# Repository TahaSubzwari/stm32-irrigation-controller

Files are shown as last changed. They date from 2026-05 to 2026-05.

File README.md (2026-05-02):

# STM32 Irrigation Controller

An embedded controller for a multi-zone irrigation system, built on the STM32 Nucleo-F401RE. The system manages a single pump and servo-driven distributor to fill a reservoir from an underground spring and irrigate three terraced zones at different elevations, all within a 24-hour cycle.

Developed for ECE 298 (Instrumentation & Prototyping Laboratory) at the University of Waterloo, Fall 2025.

---

## Features

* **Two-mode state machine** - `SETUP` mode for parameter entry over UART, `RUN` mode for autonomous 24-hour operation (scaled for demo purposes).
* **Configurable scheduling** - User specifies start/stop hours and pump speed (PWM duty cycle) for each of 4 pipelines (1 inlet + 3 zones) via serial terminal.
* **Manual control option** - Inlet pump speed can be driven by a potentiometer through ADC, mapped to PWM duty cycle in real time.
* **Servo-driven water distributor** - RGB LED indicates the active pipeline (purple/red/green/blue); servo rotates to the corresponding zone.
* **Real-time RPM measurement** - RPM pulses counted via GPIO interrupt over a fixed real-time interval (independent of the scaled simulation clock).
* **Ultrasonic depth sensing** - HC-SR04 driven by timer input capture; reservoir depth displayed as a percentage on a 7-segment timer board and over UART.
* **Empty-reservoir fault handling** - Motor shutoff and flashing white RGB indicator if the reservoir hits 0% during operation.

---

## Hardware

|Component|Role|
|-|-|
|STM32 Nucleo-F401RE|Main controller (ARM Cortex-M4)|
|L9110 motor driver + brushed DC motor|Pump, dual-direction PWM|
|SG90 servo motor|Water distributor selector|
|HC-SR04 ultrasonic sensor|Reservoir depth measurement|
|RPM Sensor + slotted wheel|RPM feedback on motor shaft|
|Lab Timer Board (dual 7-segment)|Water depth percentage display|
|RGB LED|Active pipeline indicator|
|Potentiometer|Manual speed control (inlet only)|

A custom 2-layer shield PCB was designed in Proteus to stack onto the Nucleo header. The board was not fabricated due to course timeline constraints.

---

## Hardware Design

### Schematic

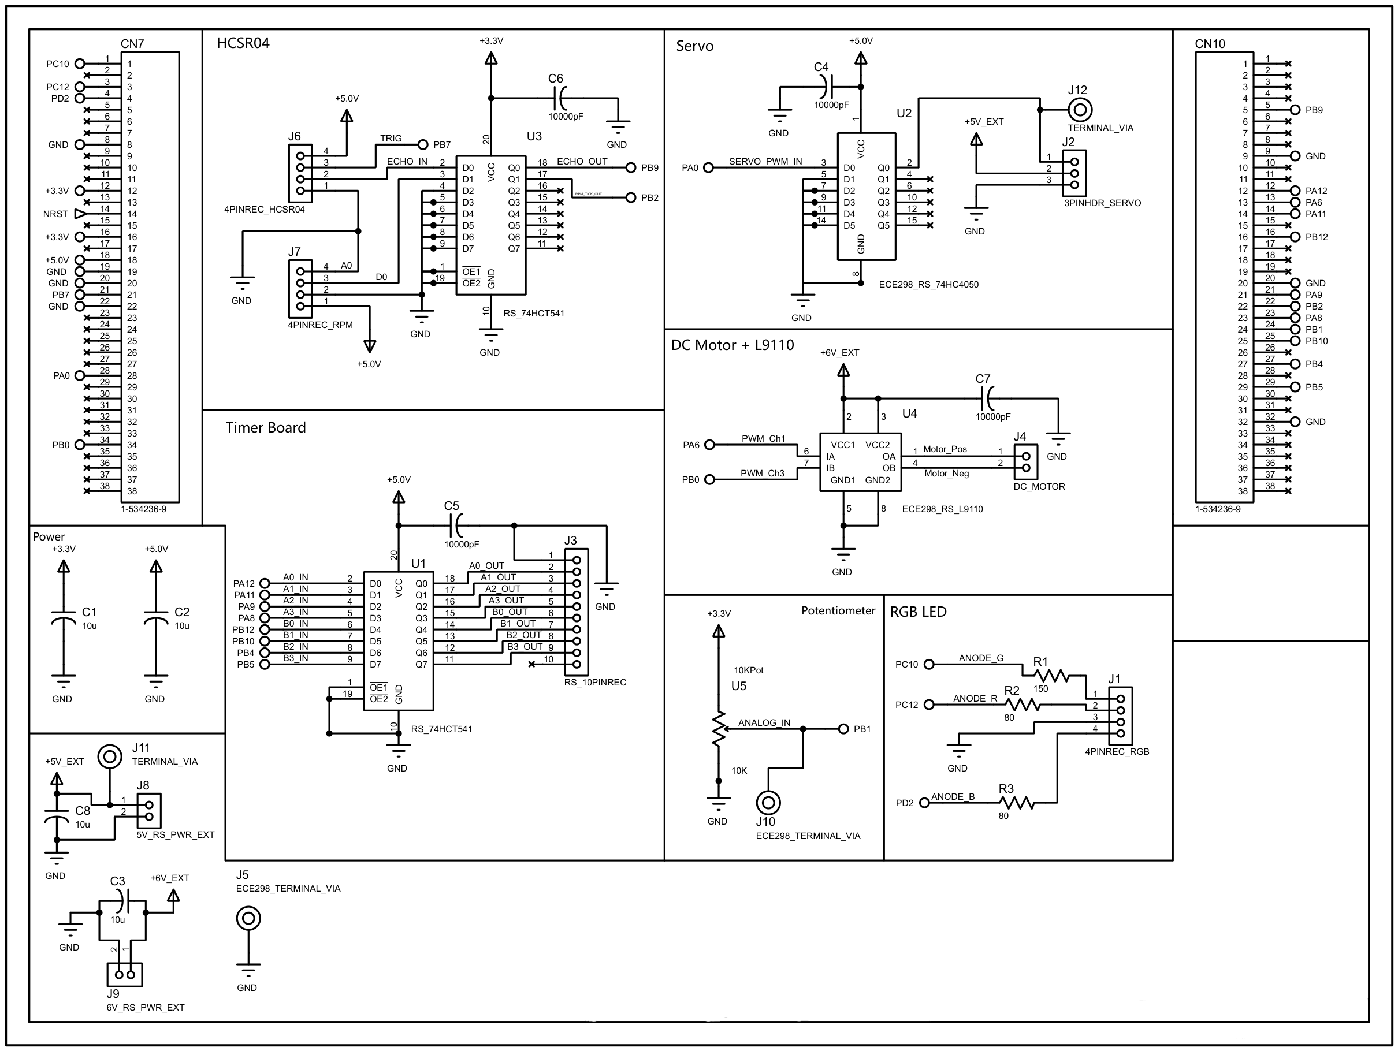
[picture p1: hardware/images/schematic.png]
Schematic


### PCB Layout

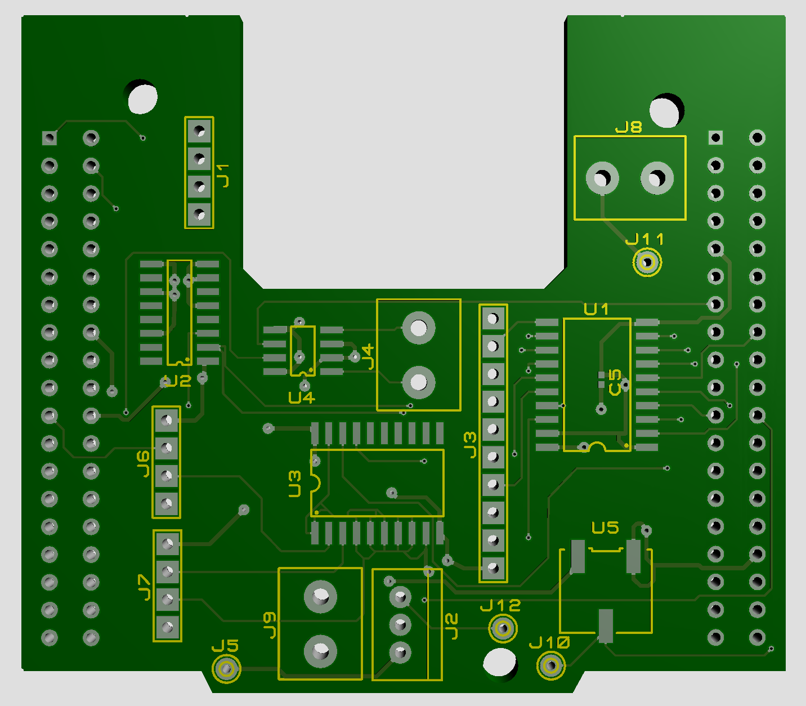
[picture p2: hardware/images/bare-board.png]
PCB Bare

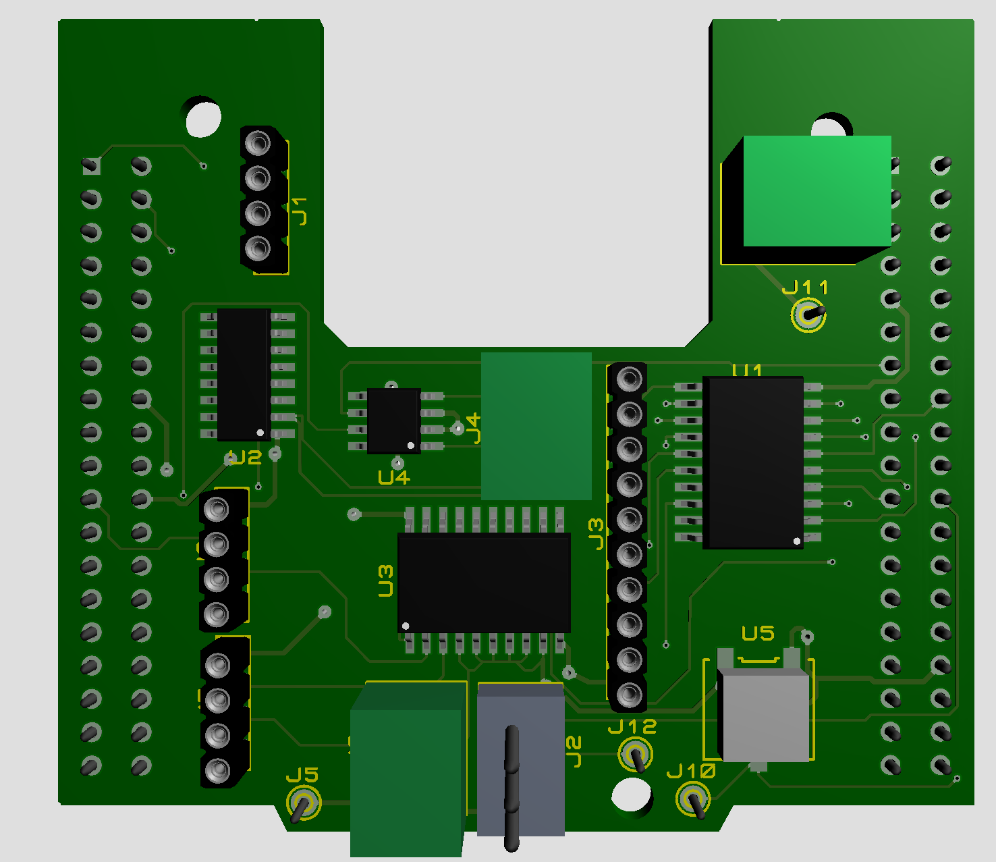
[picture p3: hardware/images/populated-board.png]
PCB Populated


---

## Architecture

### Peripherals

|Timer|Function|
|-|-|
|TIM2 CH1|Servo PWM (50 Hz, 1–2 ms pulse width)|
|TIM3 CH1/CH3|DC motor PWM (forward / reverse via L9110)|
|TIM4 CH4|HC-SR04 echo input capture (both edges)|
|TIM5|Scaled wall-clock tick (12 s = 1 simulated hour)|

|Other|Function|
|-|-|
|ADC1 CH9|Potentiometer read (8-bit resolution)|
|USART2|Terminal I/O at 115200 baud|
|EXTI (RPM\_TICK pin)|RPM pulse counter|
|GPIO|7-segment digit drive, RGB LED, mode LED, B1 button|

### Control flow

1. **Reset** → `SETUP` mode. Green LED off. UART prompts for pipeline assignments, PWM options, and start/stop hours for each of 4 pipelines.
2. Setup parameters echoed back to terminal. Green LED flashes; system waits for B1 (blue user button).
3. **B1 press** → `RUN` mode. Green LED solid on. Scaled clock starts at hour 0.
4. Each simulated hour: select active pipeline based on schedule, set servo + RGB + motor PWM, sample reservoir depth, measure RPM over real-time window, log status row to UART, update 7-segment display.
5. **Hour 24** → motor off, green LED off, system halts until reset.
6. **Reservoir empty event** → immediate motor shutoff, flashing white RGB, halt until reset.

### Status output

Hourly rows logged to UART in the format:

```
CLOCK : PIPE : PWM : RPM : DEPTH :
   0  :  0  :  0  : 142 :  87  :
   1  :  0  :  0  : 138 :  91  :
   ...
```

---

## What I'd Do Differently

This was a course project on a fixed timeline. With more time:

* **Revamp SETUP mode UART handling.** The blocking receive pattern is repeated for every prompt. A helper function or parameter table would clean this up significantly.
* **Use a struct for pipeline state.** Pipelines are tracked as parallel variables (`pipeA`, `pwmA`, `firstA`, `lastA`) instead of a single `Pipeline` struct, which inflates the schedule logic and makes adding pipelines tedious.
* **The PCB is unverified** - designed but not fabricated, so layout issues haven't been caught in hardware.

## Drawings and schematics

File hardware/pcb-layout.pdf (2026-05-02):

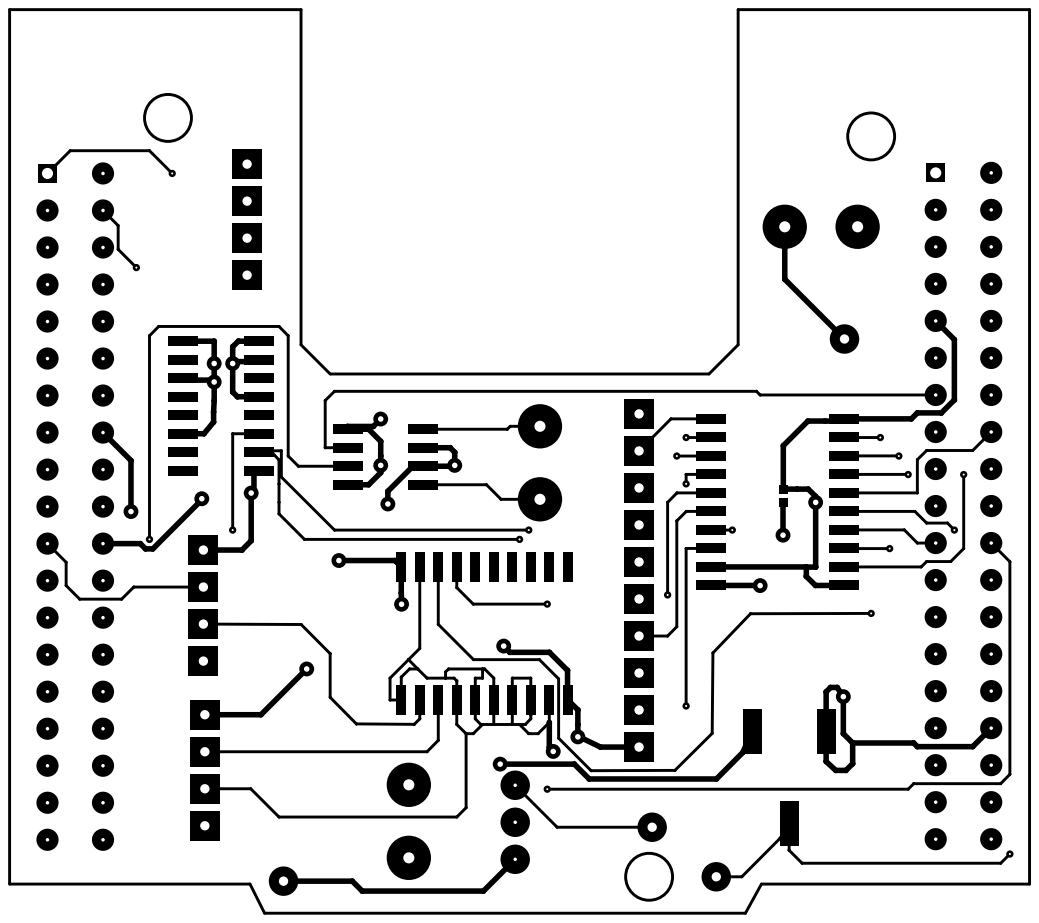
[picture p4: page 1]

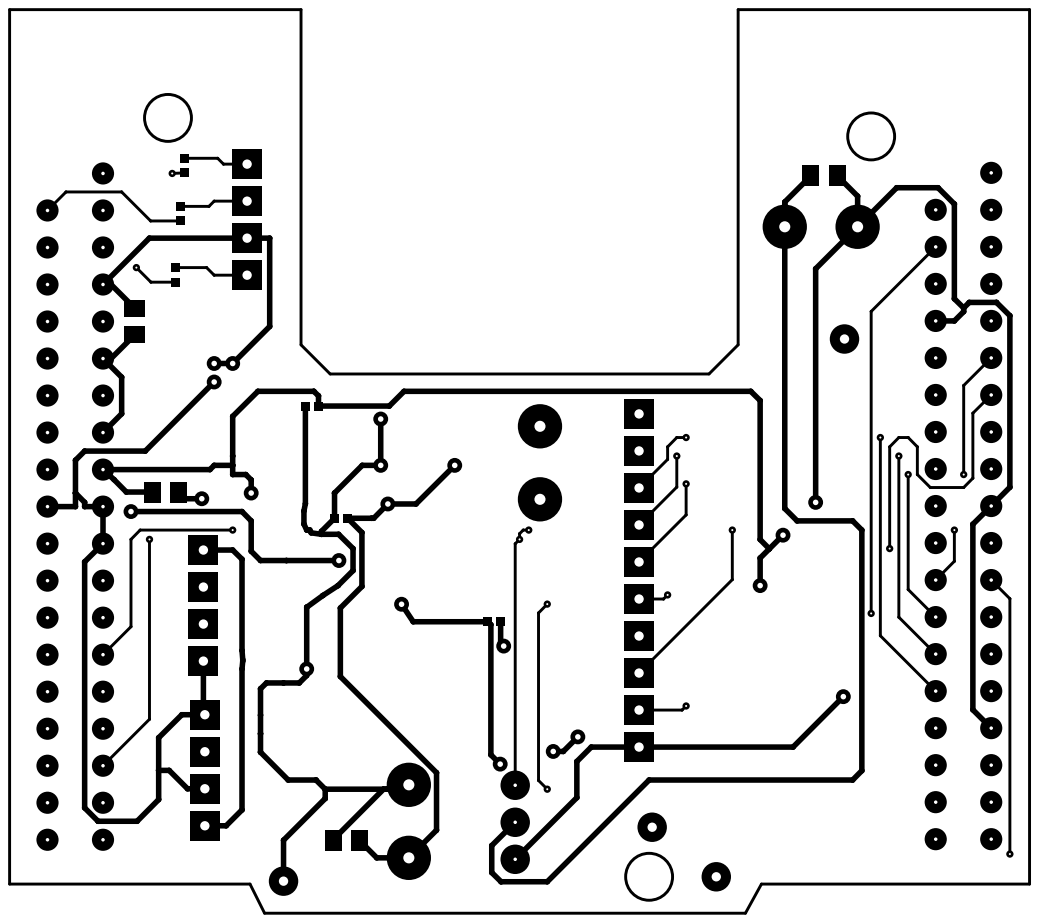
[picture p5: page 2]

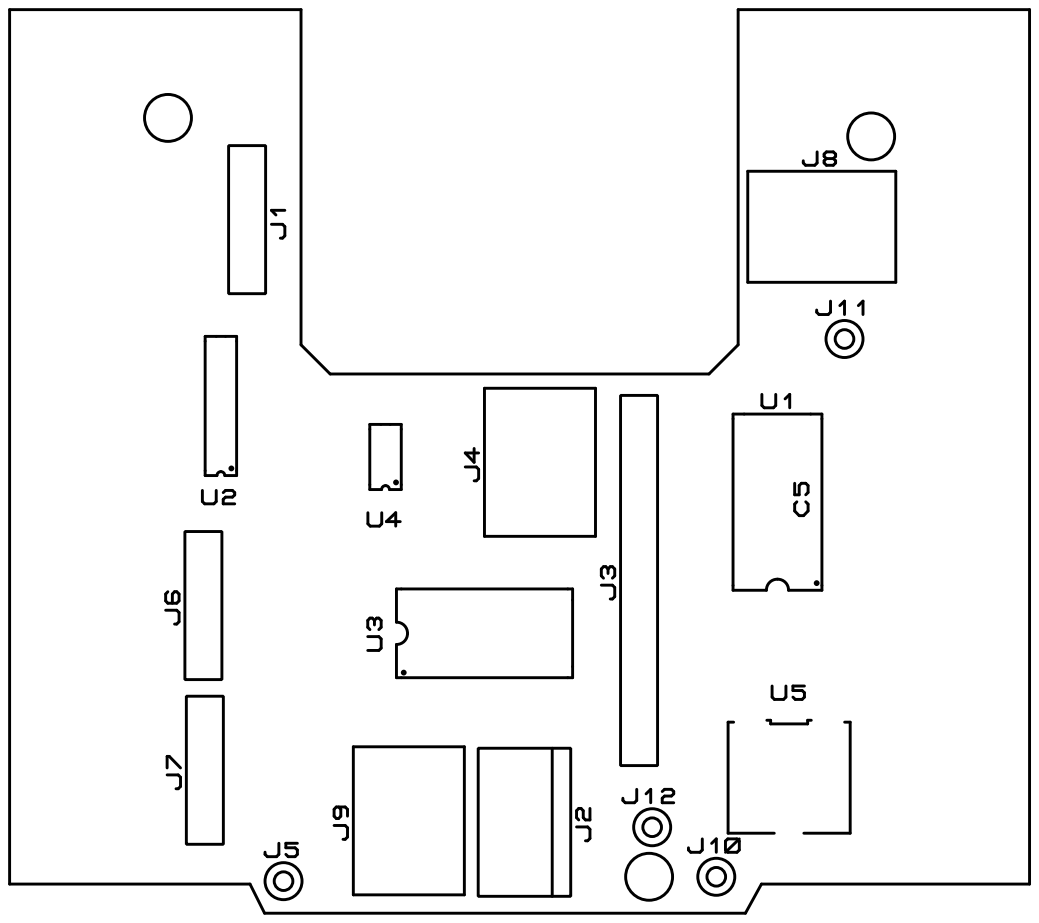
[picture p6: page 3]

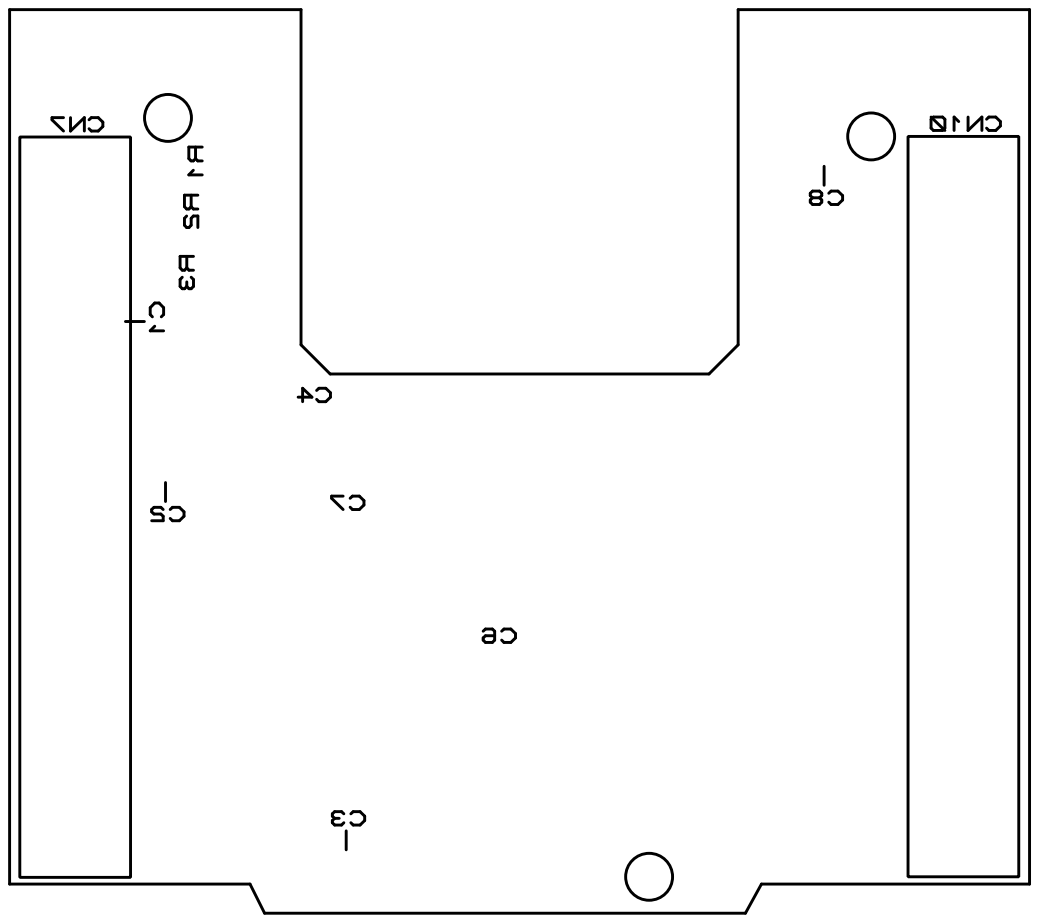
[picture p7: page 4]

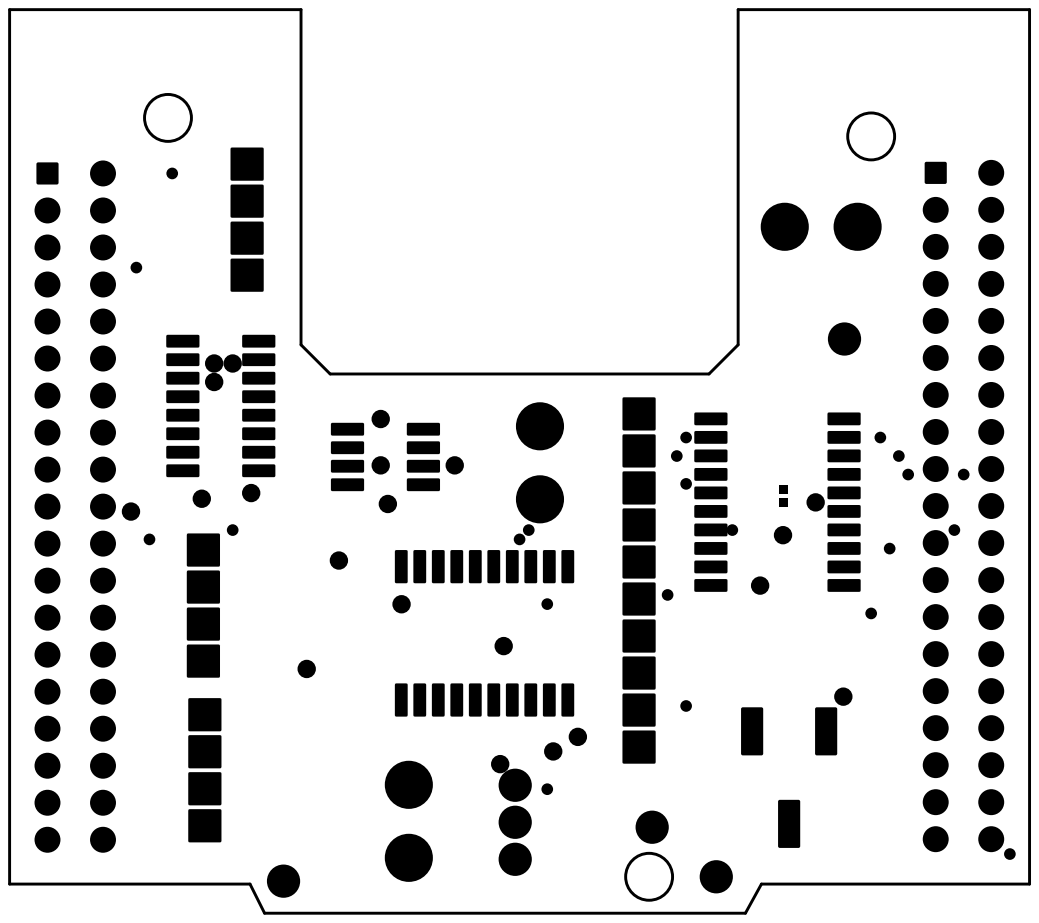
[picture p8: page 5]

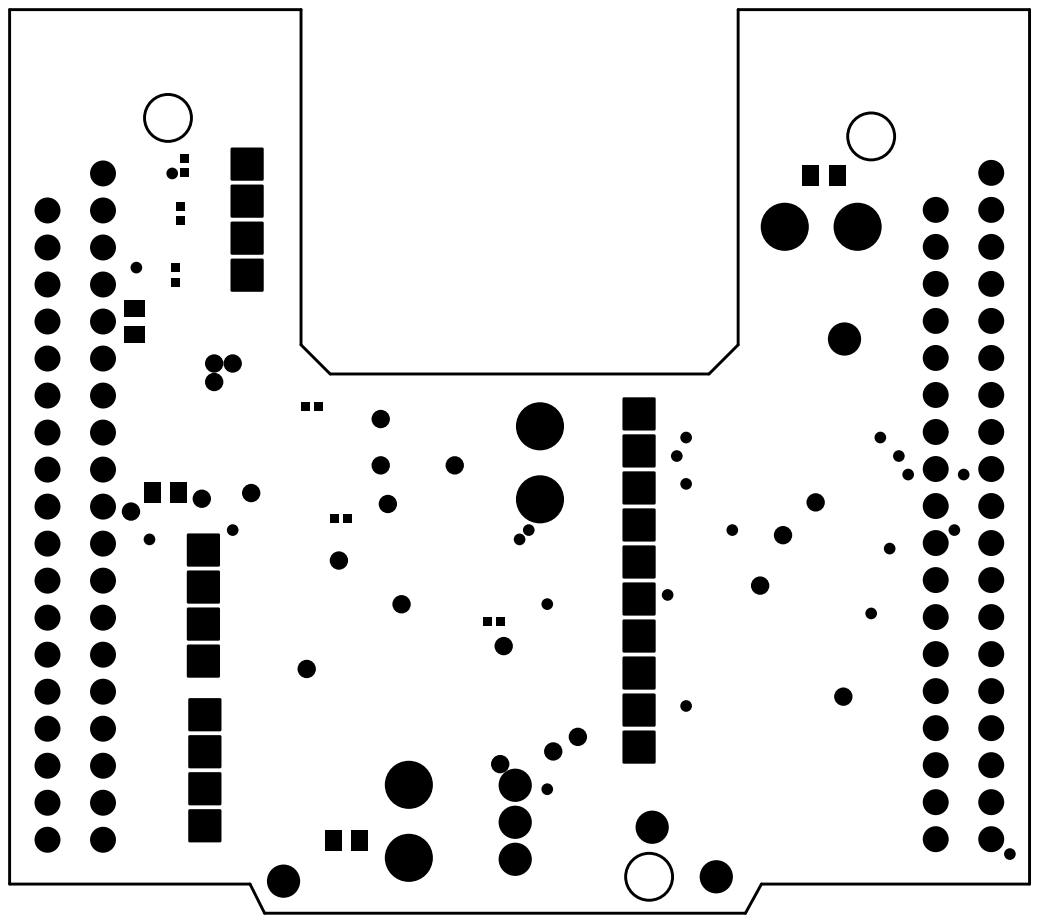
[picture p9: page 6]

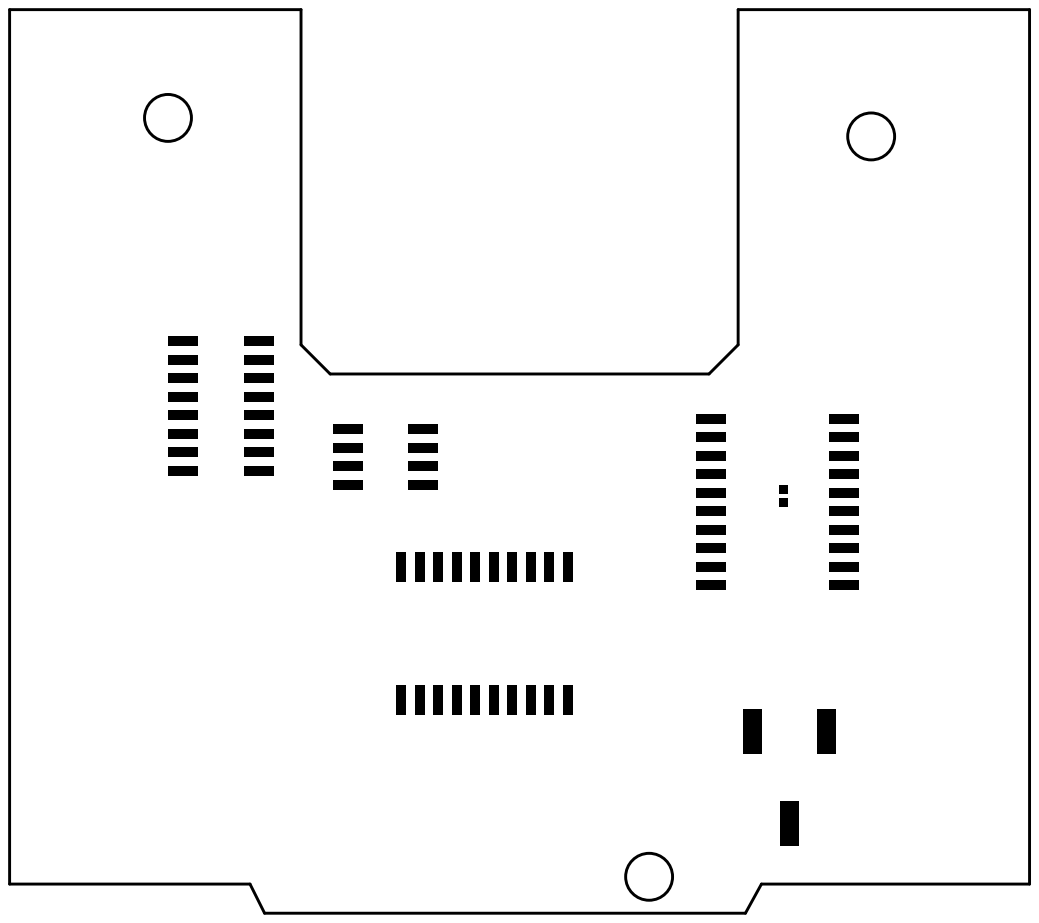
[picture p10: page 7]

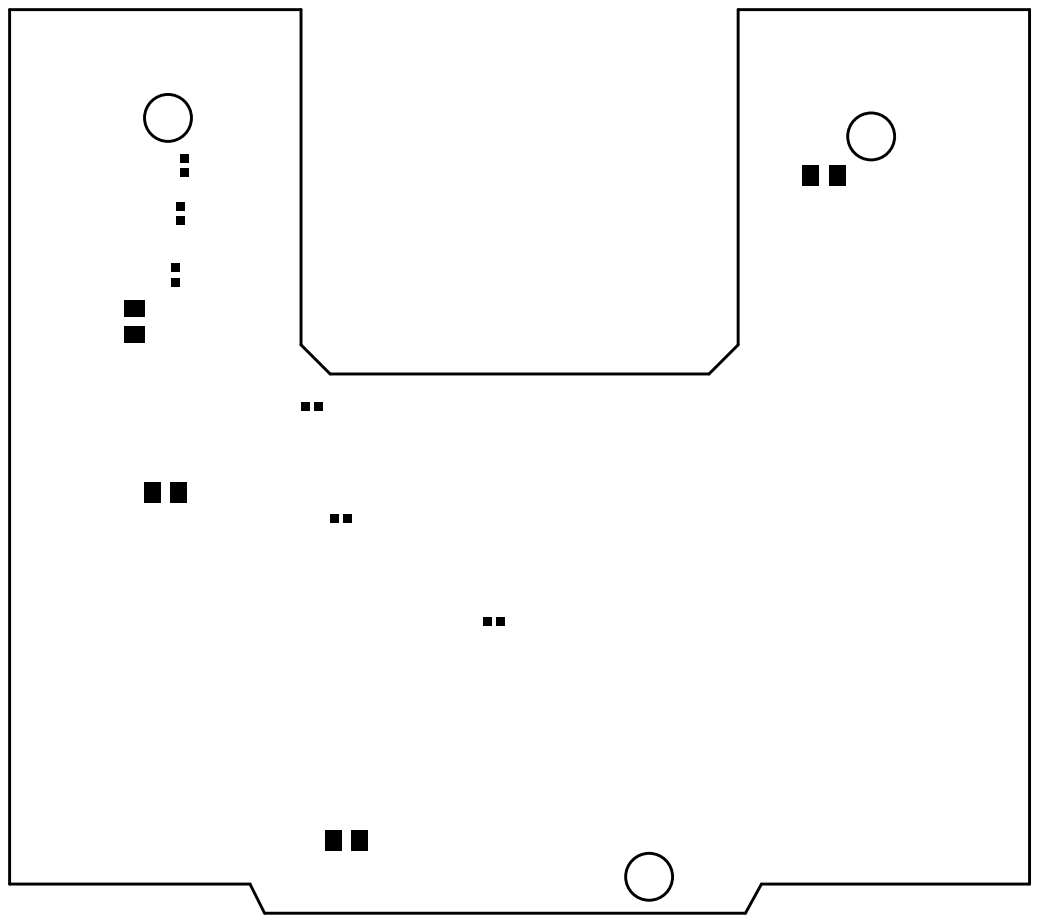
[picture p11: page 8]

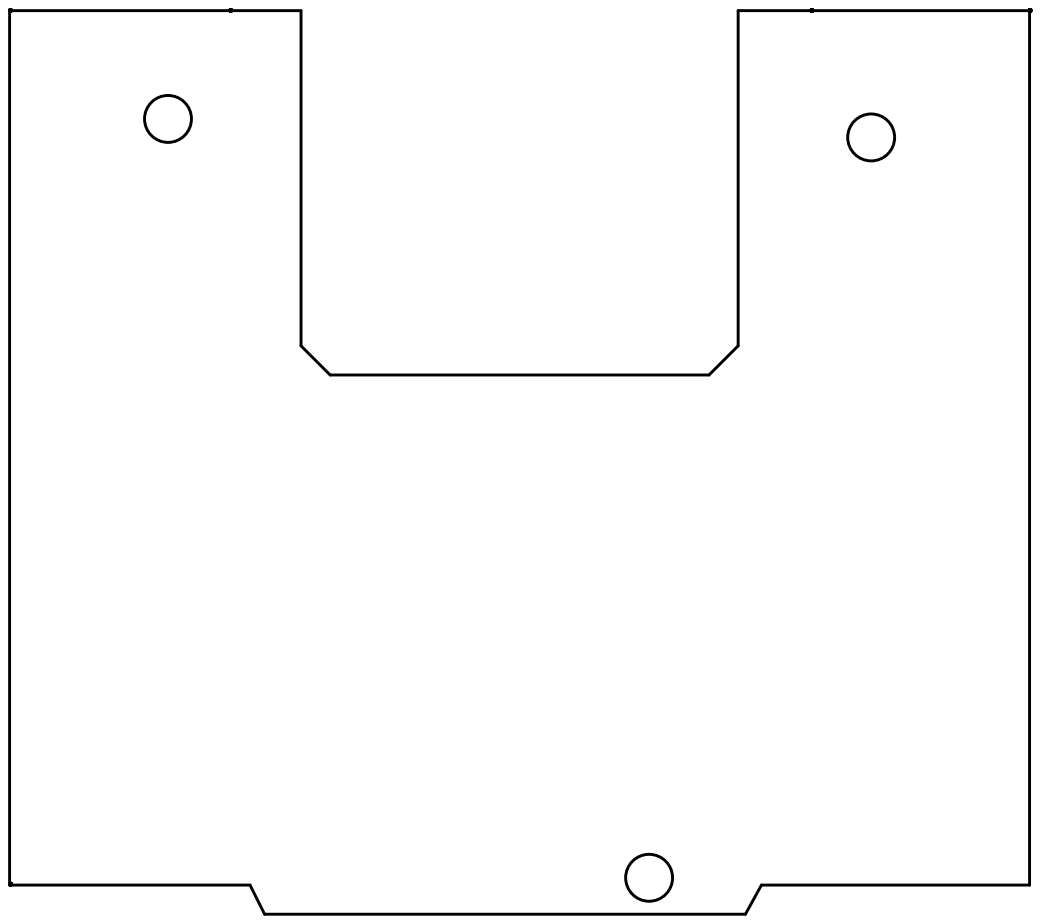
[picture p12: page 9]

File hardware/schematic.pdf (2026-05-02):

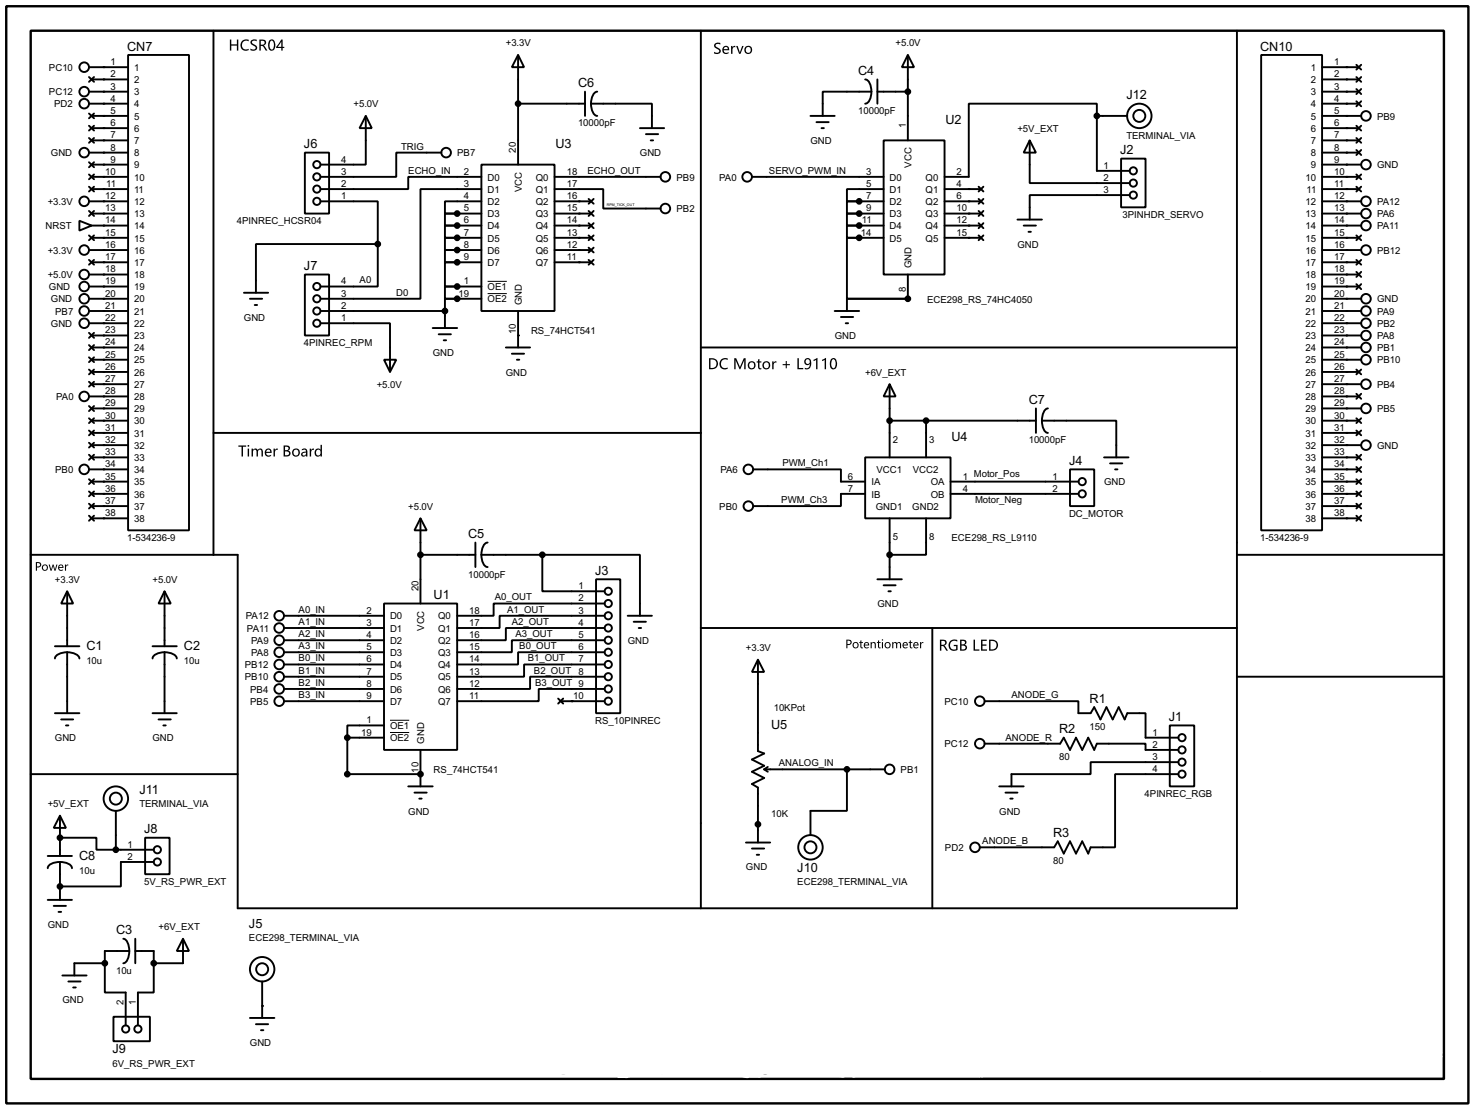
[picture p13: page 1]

C:\Users\TahaS\Downloads\ECE298_RS_Adapter.pdsprj

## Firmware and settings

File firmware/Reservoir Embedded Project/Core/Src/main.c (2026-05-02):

/* USER CODE BEGIN Header */
/**
 ******************************************************************************
 * @file    main.c
 * @brief   Main program body
 ******************************************************************************
 *
 * STM32 IRRIGATION CONTROLLER
 * ---------------------------
 * Embedded controller for an irrigation system. Manages a single pump
 * and servo-driven distributor to fill a reservoir from an underground spring
 * and irrigate three terraced zones at different elevations over a 24-hour
 * cycle.
 *
 * Target: STM32 Nucleo-F401RE (ARM Cortex-M4, 84 MHz)
 *
 *
 * SYSTEM OVERVIEW
 * ---------------
 * The system runs as a two-mode state machine:
 *
 *   SETUP MODE:  Triggered by reset (black button). User configures pipeline
 *                assignments, PWM speed options, and start/stop hours for
 *                each of 4 pipelines (1 inlet + 3 zones) over UART. Mode LED
 *                flashes; system waits for B1 (blue button) to advance.
 *
 *   RUN MODE:    Triggered by B1. Scaled wall clock starts at hour 0 and
 *                advances 300x faster than real time. Each hour, the active pipeline
 *                is selected from the schedule, the servo and RGB LED update, the motor
 *                drives at the configured PWM, and reservoir depth + RPM
 *                are sampled and logged to UART. Halts at hour 24 or on a
 *                reservoir-empty fault.
 * 
 * PERIPHERAL MAP
 * --------------
 *   TIM2 CH1   - Servo PWM (50 Hz, 1-2 ms pulse width)
 *   TIM3 CH1   - DC motor PWM, forward direction (via L9110)
 *   TIM3 CH3   - DC motor PWM, reverse direction (via L9110, inlet only)
 *   TIM4 CH4   - HC-SR04 echo input capture (both edges)
 *   TIM5       - Scaled wall-clock tick (12 s real = 1 simulated hour)
 *   ADC1 CH9   - Potentiometer (8-bit) for manual inlet speed control
 *   USART2     - Terminal I/O at 115200 baud, 8N1
 *   EXTI       - RPM_TICK pin: optical encoder pulse counter
 *   GPIO       - 7-segment digit drive (PA + PB), RGB LED (PC + PD),
 *                LD2 mode LED, B1 user button, HC-SR04 trigger
 *
 ******************************************************************************
/* USER CODE END Header */
/* Includes ------------------------------------------------------------------*/
#include "main.h"

/* USER CODE BEGIN Includes */
#include <stdio.h>
#include <string.h>
/* USER CODE END Includes */

/* USER CODE BEGIN PTD */
#define LED_RED_ON()     HAL_GPIO_WritePin(RED_GPIO_Port, RED_Pin, GPIO_PIN_SET)
#define LED_RED_OFF()    HAL_GPIO_WritePin(RED_GPIO_Port, RED_Pin, GPIO_PIN_RESET)
#define LED_GREEN_ON()   HAL_GPIO_WritePin(GREEN_GPIO_Port, GREEN_Pin, GPIO_PIN_SET)
#define LED_GREEN_OFF()  HAL_GPIO_WritePin(GREEN_GPIO_Port, GREEN_Pin, GPIO_PIN_RESET)
#define LED_BLUE_ON()    HAL_GPIO_WritePin(BLUE_GPIO_Port, BLUE_Pin, GPIO_PIN_SET)
#define LED_BLUE_OFF()   HAL_GPIO_WritePin(BLUE_GPIO_Port, BLUE_Pin, GPIO_PIN_RESET)
/* USER CODE END PTD */

/* USER CODE BEGIN PD */

//Single byte to store UART input
uint8_t byte = 0;

/* USER CODE END PD */

ADC_HandleTypeDef hadc1;

TIM_HandleTypeDef htim2;
TIM_HandleTypeDef htim3;
TIM_HandleTypeDef htim4;
TIM_HandleTypeDef htim5;

UART_HandleTypeDef huart2;

/* USER CODE BEGIN PV */
char msg[100];          // UART message buffer

//Pipeline Variables
int pipeA = 0;
int pipeB = 0;
int pipeC = 0;
int pipeD = 0;

//Pump PWN Variables
int pwmA = 0;
int pwmB = 0;
int pwmC = 0;
int pwmD = 0;

//First hour variables
int firstA = 0;
int firstB = 0;
int firstC = 0;
int firstD = 0;

//Last hour variables
int lastA = 0;
int lastB = 0;
int lastC = 0;
int lastD = 0;

char dig10 = 0;
char dig1 = 0;

uint8_t txd_msg_buffer[64] = {0};

volatile uint8_t clock_hours = 0;
volatile uint8_t wall_clock_hr_update_flag = 0;

uint16_t servo_angle_0 = 500; // Pipeline A - 0 degrees
uint16_t servo_angle_1 = 1000; // Pipeline B - 45 degrees
uint16_t servo_angle_2 = 1500; // Pipeline C - 90 degrees
uint16_t servo_angle_3 = 2000; // Pipeline D - 135 degrees

uint16_t motor_pwm_values[4] = {0, 1400, 1700, 2000}; // Adjust for motor speed levels
volatile uint32_t rpm_tick_count = 0;
volatile uint32_t measured_rpm = 0;


/* USER CODE END PV */

void SystemClock_Config(void);
static void MX_GPIO_Init(void);
static void MX_USART2_UART_Init(void);
static void MX_ADC1_Init(void);
static void MX_TIM2_Init(void);
static void MX_TIM3_Init(void);
static void MX_TIM4_Init(void);
static void MX_TIM5_Init(void);
/* USER CODE BEGIN PFP */
void Enter_Setup_Mode(void);
void Enter_Run_Mode(void);
int Measure_Distance(void);
void HCSR04_Trigger(void);
void DIGITS_Display(uint8_t DIGIT_A, uint8_t DIGIT_B);
void RGB_SetColor(uint8_t pipeline);
static void UpdateMotor(uint8_t current_pipeline, uint8_t active_pwm);
void Resevoir_Empty(void);
/* USER CODE END PFP */

/* USER CODE BEGIN 0 */
uint8_t rcv_intv_flag = 0;

volatile uint8_t hcsr04_Rx_flag = 0;
volatile uint8_t first_edge = 0;
volatile uint16_t time_edge1 = 0;
volatile uint16_t time_edge2 = 0;

float distance_cm = 0;
float distance_percent = 0;

//ENTERING SETUP MODE
void Enter_Setup_Mode(void)
{
    LED_BLUE_OFF();
    LED_GREEN_OFF();
    LED_RED_OFF();

    DIGITS_Display(0,0);

    TIM3 -> CCR1 = 0;
	TIM3 -> CCR3 = 0;

    HAL_UART_Transmit(&huart2, (uint8_t*)"\r\n=== SETUP MODE ===\r\n", 24, 1000);
    HAL_UART_Transmit(&huart2, (uint8_t*)"Enter SETUP Parameters:\r\n", 26, 1000);

    // Ask for Pipeline and PWM inputs ----------------------------------------
    sprintf((char*)txd_msg_buffer,"\r\nPipeline A (options 0 to 3): ");
    rcv_intv_flag = 0;
    HAL_UART_Receive_IT(&huart2, &byte, 1);
    HAL_UART_Transmit(&huart2, txd_msg_buffer, strlen((char*)txd_msg_buffer), 1000);
    while (rcv_intv_flag == 0) {}
    pipeA = byte - '0';

    sprintf((char*)txd_msg_buffer,"\r\nPump pwm A (options 0 to 3): ");
    rcv_intv_flag = 0;
    HAL_UART_Receive_IT(&huart2, &byte, 1);
    HAL_UART_Transmit(&huart2, txd_msg_buffer, strlen((char*)txd_msg_buffer), 1000);
    while (rcv_intv_flag == 0) {}
    pwmA = byte - '0';

    sprintf((char*)txd_msg_buffer,"\r\nPipeline B (options 0 to 3): ");
    rcv_intv_flag = 0;
    HAL_UART_Receive_IT(&huart2, &byte, 1);
    HAL_UART_Transmit(&huart2, txd_msg_buffer, strlen((char*)txd_msg_buffer), 1000);
    while (rcv_intv_flag == 0) {}
    pipeB = byte - '0';

    sprintf((char*)txd_msg_buffer,"\r\nPump pwm B (options 0 to 3): ");
    rcv_intv_flag = 0;
    HAL_UART_Receive_IT(&huart2, &byte, 1);
    HAL_UART_Transmit(&huart2, txd_msg_buffer, strlen((char*)txd_msg_buffer), 1000);
    while (rcv_intv_flag == 0) {}
    pwmB = byte - '0';

    sprintf((char*)txd_msg_buffer,"\r\nPipeline C (options 0 to 3): ");
    rcv_intv_flag = 0;
    HAL_UART_Receive_IT(&huart2, &byte, 1);
    HAL_UART_Transmit(&huart2, txd_msg_buffer, strlen((char*)txd_msg_buffer), 1000);
    while (rcv_intv_flag == 0) {}
    pipeC = byte - '0';

    sprintf((char*)txd_msg_buffer,"\r\nPump pwm C (options 0 to 3): ");
    rcv_intv_flag = 0;
    HAL_UART_Receive_IT(&huart2, &byte, 1);
    HAL_UART_Transmit(&huart2, txd_msg_buffer, strlen((char*)txd_msg_buffer), 1000);
    while (rcv_intv_flag == 0) {}
    pwmC = byte - '0';

    sprintf((char*)txd_msg_buffer,"\r\nPipeline D (options 0 to 3): ");
    rcv_intv_flag = 0;
    HAL_UART_Receive_IT(&huart2, &byte, 1);
    HAL_UART_Transmit(&huart2, txd_msg_buffer, strlen((char*)txd_msg_buffer), 1000);
    while (rcv_intv_flag == 0) {}
    pipeD = byte - '0';

    sprintf((char*)txd_msg_buffer,"\r\nPump pwm D (options 0 to 3): ");
    rcv_intv_flag = 0;
    HAL_UART_Receive_IT(&huart2, &byte, 1);
    HAL_UART_Transmit(&huart2, txd_msg_buffer, strlen((char*)txd_msg_buffer), 1000);
    while (rcv_intv_flag == 0) {}
    pwmD = byte - '0';

    //--------------------------------------------------------------------------------------

    //Ask for first and last hour of each pipeline
    sprintf((char*)txd_msg_buffer, "\r\nPipeline 0 Pump FIRST HOUR (options: 00 to 23): ");
    rcv_intv_flag = 0;
	HAL_UART_Receive_IT(&huart2, &byte, 1);
	HAL_UART_Transmit(&huart2, txd_msg_buffer, strlen((char*)txd_msg_buffer), 1000);
	while (rcv_intv_flag == 0) {}
	dig10 = byte;
	rcv_intv_flag = 0;
	rcv_intv_flag = 0;
	HAL_UART_Receive_IT(&huart2, &byte, 1);
	while (rcv_intv_flag == 0) {}
	dig1 = byte;
	rcv_intv_flag = 0;

	firstA = (dig10-'0')*10 + (dig1 - '0');

    sprintf((char*)txd_msg_buffer, "\r\nPipeline 0 Pump LAST HOUR (options: 00 to 23): ");
    rcv_intv_flag = 0;
	HAL_UART_Receive_IT(&huart2, &byte, 1);
	HAL_UART_Transmit(&huart2, txd_msg_buffer, strlen((char*)txd_msg_buffer), 1000);
	while (rcv_intv_flag == 0) {}
	dig10 = byte;
	rcv_intv_flag = 0;
	rcv_intv_flag = 0;
	HAL_UART_Receive_IT(&huart2, &byte, 1);
	while (rcv_intv_flag == 0) {}
	dig1 = byte;
	rcv_intv_flag = 0;

	lastA = (dig10-'0')*10 + (dig1 - '0');

    sprintf((char*)txd_msg_buffer, "\r\nPipeline 1 Pump FIRST HOUR (options: 00 to 23): ");
    rcv_intv_flag = 0;
	HAL_UART_Receive_IT(&huart2, &byte, 1);
	HAL_UART_Transmit(&huart2, txd_msg_buffer, strlen((char*)txd_msg_buffer), 1000);
	while (rcv_intv_flag == 0) {}
	dig10 = byte;
	rcv_intv_flag = 0;
	rcv_intv_flag = 0;
	HAL_UART_Receive_IT(&huart2, &byte, 1);
	while (rcv_intv_flag == 0) {}
	dig1 = byte;
	rcv_intv_flag = 0;

	firstB = (dig10-'0')*10 + (dig1 - '0');

    sprintf((char*)txd_msg_buffer, "\r\nPipeline 1 Pump LAST HOUR (options: 00 to 23): ");
    rcv_intv_flag = 0;
	HAL_UART_Receive_IT(&huart2, &byte, 1);
	HAL_UART_Transmit(&huart2, txd_msg_buffer, strlen((char*)txd_msg_buffer), 1000);
	while (rcv_intv_flag == 0) {}
	dig10 = byte;
	rcv_intv_flag = 0;
	rcv_intv_flag = 0;
	HAL_UART_Receive_IT(&huart2, &byte, 1);
	while (rcv_intv_flag == 0) {}
	dig1 = byte;
	rcv_intv_flag = 0;

	lastB = (dig10-'0')*10 + (dig1 - '0');

	sprintf((char*)txd_msg_buffer, "\r\nPipeline 2 Pump FIRST HOUR (options: 00 to 23): ");
    rcv_intv_flag = 0;
	HAL_UART_Receive_IT(&huart2, &byte, 1);
	HAL_UART_Transmit(&huart2, txd_msg_buffer, strlen((char*)txd_msg_buffer), 1000);
	while (rcv_intv_flag == 0) {}
	dig10 = byte;
	rcv_intv_flag = 0;
	rcv_intv_flag = 0;
	HAL_UART_Receive_IT(&huart2, &byte, 1);
	while (rcv_intv_flag == 0) {}
	dig1 = byte;
	rcv_intv_flag = 0;

	firstC = (dig10-'0')*10 + (dig1 - '0');

	sprintf((char*)txd_msg_buffer, "\r\nPipeline 2 Pump LAST HOUR (options: 00 to 23): ");
    rcv_intv_flag = 0;
	HAL_UART_Receive_IT(&huart2, &byte, 1);
	HAL_UART_Transmit(&huart2, txd_msg_buffer, strlen((char*)txd_msg_buffer), 1000);
	while (rcv_intv_flag == 0) {}
	dig10 = byte;
	rcv_intv_flag = 0;
	rcv_intv_flag = 0;
	HAL_UART_Receive_IT(&huart2, &byte, 1);
	while (rcv_intv_flag == 0) {}
	dig1 = byte;
	rcv_intv_flag = 0;

	lastC = (dig10-'0')*10 + (dig1 - '0');

	sprintf((char*)txd_msg_buffer, "\r\nPipeline 3 Pump FIRST HOUR (options: 00 to 23): ");
    rcv_intv_flag = 0;
	HAL_UART_Receive_IT(&huart2, &byte, 1);
	HAL_UART_Transmit(&huart2, txd_msg_buffer, strlen((char*)txd_msg_buffer), 1000);
	while (rcv_intv_flag == 0) {}
	dig10 = byte;
	rcv_intv_flag = 0;
	rcv_intv_flag = 0;
	HAL_UART_Receive_IT(&huart2, &byte, 1);
	while (rcv_intv_flag == 0) {}
	dig1 = byte;
	rcv_intv_flag = 0;

	firstD = (dig10-'0')*10 + (dig1 - '0');

	sprintf((char*)txd_msg_buffer, "\r\nPipeline 3 Pump LAST HOUR (options: 00 to 23): ");
    rcv_intv_flag = 0;
	HAL_UART_Receive_IT(&huart2, &byte, 1);
	HAL_UART_Transmit(&huart2, txd_msg_buffer, strlen((char*)txd_msg_buffer), 1000);
	while (rcv_intv_flag == 0) {}
	dig10 = byte;
	rcv_intv_flag = 0;
	rcv_intv_flag = 0;
	HAL_UART_Receive_IT(&huart2, &byte, 1);
	while (rcv_intv_flag == 0) {}
	dig1 = byte;
	rcv_intv_flag = 0;

	lastD = (dig10-'0')*10 + (dig1 - '0');

	//------------------------------------------------------------------------
	//Output all the information and wait for user to press blue button
	sprintf((char*)txd_msg_buffer, "\t\n\nPrinting SETUP Parameters\n\n");
	HAL_UART_Transmit(&huart2, txd_msg_buffer, strlen((char*)txd_msg_buffer), 1000);

	sprintf((char*)txd_msg_buffer, "\n\rCURRENT WALL CLOCK HOUR 0\n");
	HAL_UART_Transmit(&huart2, txd_msg_buffer, strlen((char*)txd_msg_buffer), 1000);

	sprintf((char*)txd_msg_buffer, "\n\rPipeline: %d ", pipeA);
	HAL_UART_Transmit(&huart2, txd_msg_buffer, strlen((char*)txd_msg_buffer), 1000);

	sprintf((char*)txd_msg_buffer, "Pump PWM: %d ", pwmA);
	HAL_UART_Transmit(&huart2, txd_msg_buffer, strlen((char*)txd_msg_buffer), 1000);

	sprintf((char*)txd_msg_buffer, "Pump FIRST Hour: %d Pump LAST Hour %d\n", firstA, lastA);
	HAL_UART_Transmit(&huart2, txd_msg_buffer, strlen((char*)txd_msg_buffer), 1000);


	sprintf((char*)txd_msg_buffer, "\n\rPipeline: %d ", pipeB);
	HAL_UART_Transmit(&huart2, txd_msg_buffer, strlen((char*)txd_msg_buffer), 1000);

	sprintf((char*)txd_msg_buffer, "Pump PWM: %d ", pwmB);
	HAL_UART_Transmit(&huart2, txd_msg_buffer, strlen((char*)txd_msg_buffer), 1000);

	sprintf((char*)txd_msg_buffer, "Pump FIRST Hour: %d Pump LAST Hour %d\n", firstB, lastB);
	HAL_UART_Transmit(&huart2, txd_msg_buffer, strlen((char*)txd_msg_buffer), 1000);


	sprintf((char*)txd_msg_buffer, "\n\rPipeline: %d ", pipeC);
	HAL_UART_Transmit(&huart2, txd_msg_buffer, strlen((char*)txd_msg_buffer), 1000);

	sprintf((char*)txd_msg_buffer, "Pump PWM: %d ", pwmC);
	HAL_UART_Transmit(&huart2, txd_msg_buffer, strlen((char*)txd_msg_buffer), 1000);

	sprintf((char*)txd_msg_buffer, "Pump FIRST Hour: %d Pump LAST Hour %d\n", firstC, lastC);
	HAL_UART_Transmit(&huart2, txd_msg_buffer, strlen((char*)txd_msg_buffer), 1000);


	sprintf((char*)txd_msg_buffer, "\n\rPipeline: %d ", pipeD);
	HAL_UART_Transmit(&huart2, txd_msg_buffer, strlen((char*)txd_msg_buffer), 1000);

	sprintf((char*)txd_msg_buffer, "Pump PWM: %d ", pwmD);
	HAL_UART_Transmit(&huart2, txd_msg_buffer, strlen((char*)txd_msg_buffer), 1000);

	sprintf((char*)txd_msg_buffer, "Pump FIRST Hour: %d Pump LAST Hour %d\n", firstD, lastD);
	HAL_UART_Transmit(&huart2, txd_msg_buffer, strlen((char*)txd_msg_buffer), 1000);


	sprintf((char*)txd_msg_buffer, "\n\n\rSETUP is done. Press Blue Button for RUN MODE");
	HAL_UART_Transmit(&huart2, txd_msg_buffer, strlen((char*)txd_msg_buffer), 1000);


	while(1){
		GPIO_PinState buttonState = HAL_GPIO_ReadPin(GPIOC, GPIO_PIN_13);

		HAL_GPIO_WritePin(GPIOA, GPIO_PIN_5, GPIO_PIN_SET);		//LED is ON
		HAL_Delay(100);
		HAL_GPIO_WritePin(GPIOA, GPIO_PIN_5, GPIO_PIN_RESET);	//LED is OFF
		HAL_Delay(100);

		if(buttonState == GPIO_PIN_RESET){
			break;
		}
	}

}

//Send pulse
void HCSR04_Trigger(void)
{
    HAL_GPIO_WritePin(HCSR04_TRIG_GPIO_Port, HCSR04_TRIG_Pin, GPIO_PIN_SET);
    for (int j = 0; j < 15; j++) {};  // 10µs pulse
    HAL_GPIO_WritePin(HCSR04_TRIG_GPIO_Port, HCSR04_TRIG_Pin, GPIO_PIN_RESET);
}



//------------------MEASURE DISTANCE AS PERCENTAGE-----------------------
int Measure_Distance(void) {

	uint16_t time_diff = 0;
	hcsr04_Rx_flag = 0;
	first_edge = 0;
	time_edge1 = 0;
	time_edge2 = 0;

	HCSR04_Trigger();

	//Wait for measurement
	while (hcsr04_Rx_flag == 0) {}

	//Compute pulse difference
	if (time_edge2 > time_edge1)
	time_diff = time_edge2 - time_edge1;

	//Convert to cm (based on datasheet: time/58)
	distance_cm = 88 - (time_diff / 58.0f);
	if(distance_cm < 0.0f){
		distance_cm = 0.0f;
	}

	//Compute percentage from max distance
	distance_percent = (distance_cm / 88.0f) * 100.0f;

	return (uint16_t)distance_percent;
}

void Set_Servo_Angle(uint16_t pulse_width)
{
    __HAL_TIM_SET_COMPARE(&htim2, TIM_CHANNEL_1, pulse_width);
}


//-------------------DISPLAY DISTANCE PERCENTAGE ON 7 SEG----------------
void DIGITS_Display(uint8_t DIGIT_A, uint8_t DIGIT_B) {
    DIGIT_A &= 0x0F;
    DIGIT_B &= 0x0F;

    // Pipeline A (tens digit) - Port A
    HAL_GPIO_WritePin(GPIOA, DIGIT_A0_Pin, (DIGIT_A & 0x1) ? GPIO_PIN_SET : GPIO_PIN_RESET);
    HAL_GPIO_WritePin(GPIOA, DIGIT_A1_Pin, (DIGIT_A & 0x2) ? GPIO_PIN_SET : GPIO_PIN_RESET);
    HAL_GPIO_WritePin(GPIOA, DIGIT_A2_Pin, (DIGIT_A & 0x4) ? GPIO_PIN_SET : GPIO_PIN_RESET);
    HAL_GPIO_WritePin(GPIOA, DIGIT_A3_Pin, (DIGIT_A & 0x8) ? GPIO_PIN_SET : GPIO_PIN_RESET);

    // Pipeline B (ones digit) - Port B
    HAL_GPIO_WritePin(GPIOB, DIGIT_B0_Pin, (DIGIT_B & 0x1) ? GPIO_PIN_SET : GPIO_PIN_RESET);
    HAL_GPIO_WritePin(GPIOB, DIGIT_B1_Pin, (DIGIT_B & 0x2) ? GPIO_PIN_SET : GPIO_PIN_RESET);
    HAL_GPIO_WritePin(GPIOB, DIGIT_B2_Pin, (DIGIT_B & 0x4) ? GPIO_PIN_SET : GPIO_PIN_RESET);
    HAL_GPIO_WritePin(GPIOB, DIGIT_B3_Pin, (DIGIT_B & 0x8) ? GPIO_PIN_SET : GPIO_PIN_RESET);
}


//---------------------SET RBG LED COLOR---------------------------------
void RGB_SetColor(uint8_t pipeline)
{
    // Turn all LEDs OFF first
    LED_RED_OFF();
    LED_GREEN_OFF();
    LED_BLUE_OFF();

    if (pipeline == 0)
    {
        LED_RED_ON();                   // Pipeline 0 PURPLE
        LED_BLUE_ON();
    }
    else if (pipeline == 1)
    {
        LED_RED_ON();                 // Pipeline 1 RED
    }
    else if (pipeline == 2)
    {
        LED_GREEN_ON();                  // Pipeline 2 GREEN
    }
    else if (pipeline == 3)
    {
        LED_BLUE_ON();                 // Pipeline 3 BLUE
    }
    else
    {
        LED_RED_OFF();
        LED_GREEN_OFF();
        LED_BLUE_OFF();

    }
}


//----------------------UPDATE MOTOR CONTINUALLY-------------------------
static void UpdateMotor(uint8_t current_pipeline, uint8_t active_pwm){
	if (current_pipeline == 0 && active_pwm == 0)
		{
		// Start conversion, wait briefly, read value
		HAL_ADC_Start(&hadc1);

		if (HAL_ADC_PollForConversion(&hadc1, 10) == HAL_OK) {
			uint32_t pot_value = HAL_ADC_GetValue(&hadc1); // 0-255

			// Map to TIM3 CCR range (TIM3 period = 2000)
			uint16_t scaled_pwm = (uint16_t)((pot_value * 2000UL) / 255UL);

			// Apply to TIM3 channel 3
			TIM3->CCR3 = scaled_pwm;

			// ensure other channel is off
			TIM3->CCR1 = 0;
		}
		HAL_ADC_Stop(&hadc1);
	}
}


//---------------------SPECIAL EVENT------------------------------------
void Reservoir_Empty(void) {
		//Stop motion
	    TIM3->CCR1 = 0;
	    TIM3->CCR3 = 0;

	    //Board LED off
	    HAL_GPIO_WritePin(GPIOA, GPIO_PIN_5, GPIO_PIN_RESET);

		sprintf((char*)txd_msg_buffer, "\r\n Reservoir is EMPTY! \r\n");
		HAL_UART_Transmit(&huart2, txd_msg_buffer, strlen((char*)txd_msg_buffer), 1000);

	    //Flash white
	    while (1)
	    {
	        //Digits display 00
	        DIGITS_Display(0,0);

	        LED_RED_ON();
	        LED_GREEN_ON();
	        LED_BLUE_ON();
	        HAL_Delay(250);
	        LED_RED_OFF();
	        LED_GREEN_OFF();
	        LED_BLUE_OFF();
	        HAL_Delay(250);


	    }
}
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
int main(void)
{

  /* MCU Configuration--------------------------------------------------------*/

  /* Reset of all peripherals, Initializes the Flash interface and the Systick. */
  HAL_Init();

  /* Configure the system clock */
  SystemClock_Config();

  /* Initialize all configured peripherals */
  MX_GPIO_Init();
  MX_USART2_UART_Init();
  MX_ADC1_Init();
  MX_TIM2_Init();
  MX_TIM3_Init();
  MX_TIM4_Init();
  MX_TIM5_Init();
  /* USER CODE BEGIN 2 */
  HAL_TIM_Base_Init(&htim4);
  HAL_TIM_Base_Start(&htim4);
  HAL_TIM_IC_Start_IT(&htim4, TIM_CHANNEL_4);
  HAL_TIM_PWM_Start(&htim2, TIM_CHANNEL_1);
  HAL_TIM_PWM_Start(&htim3, TIM_CHANNEL_1);
  HAL_TIM_PWM_Start(&htim3, TIM_CHANNEL_3);


  Enter_Setup_Mode();
  HAL_GPIO_WritePin(GPIOA, GPIO_PIN_5, GPIO_PIN_SET);		//LED is ON
  Enter_Run_Mode();
  /* USER CODE END 2 */

  /* Infinite loop */
  /* USER CODE BEGIN WHILE */
  while (1)
  {

    /* USER CODE END WHILE */

    /* USER CODE BEGIN 3 */
  }
  /* USER CODE END 3 */
}

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
/* USER CODE BEGIN 4 */
void HAL_UART_RxCpltCallback(UART_HandleTypeDef *huart) {
	if (huart -> Instance == USART2) {
		HAL_UART_Transmit(&huart2, &byte, 1, 100);
		rcv_intv_flag = 1;
	}
}

void HAL_TIM_IC_CaptureCallback(TIM_HandleTypeDef *htim)
{
    if (htim->Instance == TIM4)
    {
        if (htim->Channel == HAL_TIM_ACTIVE_CHANNEL_4)
        {
            if (first_edge == 0)
            {
                time_edge1 = HAL_TIM_ReadCapturedValue(htim, TIM_CHANNEL_4);
                first_edge = 1;
            }
            else
            {
                time_edge2 = HAL_TIM_ReadCapturedValue(htim, TIM_CHANNEL_4);
                __HAL_TIM_SET_COUNTER(htim, 0);
                hcsr04_Rx_flag = 1;
            }
        }
    }
}

void HAL_TIM_PeriodElapsedCallback(TIM_HandleTypeDef *htim)
{
    if (htim->Instance == TIM5)
    {
    	clock_hours++;
        wall_clock_hr_update_flag = 1; // trigger display update

    }
}

void HAL_GPIO_EXTI_Callback(uint16_t GPIO_Pin)
{
    if (GPIO_Pin == RPM_TICK_Pin)
    {
        rpm_tick_count++;
    }
}


/* USER CODE END 4 */
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


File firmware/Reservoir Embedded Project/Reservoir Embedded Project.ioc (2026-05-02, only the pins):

Mcu.UserName=STM32F401RETx
PA0-WKUP.Signal=S_TIM2_CH1_ETR
PA11.GPIO_Label=DIGIT_A1
PA11.Signal=GPIO_Output
PA12.GPIO_Label=DIGIT_A0
PA12.Signal=GPIO_Output
PA13.GPIO_Label=TMS
PA13.Signal=SYS_JTMS-SWDIO
PA14.GPIO_Label=TCK
PA14.Signal=SYS_JTCK-SWCLK
PA2.GPIO_Label=USART_TX
PA2.Signal=USART2_TX
PA3.GPIO_Label=USART_RX
PA3.Signal=USART2_RX
PA5.GPIO_Label=LD2 [Green Led]
PA5.Signal=GPIO_Output
PA6.Signal=S_TIM3_CH1
PA8.GPIO_Label=DIGIT_A3
PA8.Signal=GPIO_Output
PA9.GPIO_Label=DIGIT_A2
PA9.Signal=GPIO_Output
PB0.Signal=S_TIM3_CH3
PB1.Signal=ADCx_IN9
PB10.GPIO_Label=DIGIT_B1
PB10.Signal=GPIO_Output
PB2.GPIO_Label=RPM_TICK
PB2.Signal=GPXTI2
PB3.GPIO_Label=SWO
PB3.Signal=SYS_JTDO-SWO
PB4.GPIO_Label=DIGIT_B2
PB4.Signal=GPIO_Output
PB5.GPIO_Label=DIGIT_B3
PB5.Signal=GPIO_Output
PB6.GPIO_Label=DIGIT_B0
PB6.Signal=GPIO_Output
PB8.GPIO_Label=HCSR04_TRIG
PB8.Signal=GPIO_Output
PB9.Signal=S_TIM4_CH4
PC10.GPIO_Label=RED
PC10.Signal=GPIO_Output
PC12.GPIO_Label=GREEN
PC12.Signal=GPIO_Output
PC13-ANTI_TAMP.GPIO_Label=B1 [Blue PushButton]
PC13-ANTI_TAMP.Signal=GPXTI13
PC14-OSC32_IN.Signal=RCC_OSC32_IN
PC15-OSC32_OUT.Signal=RCC_OSC32_OUT
PD2.GPIO_Label=BLUE
PD2.Signal=GPIO_Output

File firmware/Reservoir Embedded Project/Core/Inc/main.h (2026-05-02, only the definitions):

#define B1_Pin GPIO_PIN_13
#define B1_GPIO_Port GPIOC
#define B1_EXTI_IRQn EXTI15_10_IRQn
#define USART_TX_Pin GPIO_PIN_2
#define USART_TX_GPIO_Port GPIOA
#define USART_RX_Pin GPIO_PIN_3
#define USART_RX_GPIO_Port GPIOA
#define LD2_Pin GPIO_PIN_5
#define LD2_GPIO_Port GPIOA
#define RPM_TICK_Pin GPIO_PIN_2
#define RPM_TICK_GPIO_Port GPIOB
#define RPM_TICK_EXTI_IRQn EXTI2_IRQn
#define DIGIT_B1_Pin GPIO_PIN_10
#define DIGIT_B1_GPIO_Port GPIOB
#define DIGIT_A3_Pin GPIO_PIN_8
#define DIGIT_A3_GPIO_Port GPIOA
#define DIGIT_A2_Pin GPIO_PIN_9
#define DIGIT_A2_GPIO_Port GPIOA
#define DIGIT_A1_Pin GPIO_PIN_11
#define DIGIT_A1_GPIO_Port GPIOA
#define DIGIT_A0_Pin GPIO_PIN_12
#define DIGIT_A0_GPIO_Port GPIOA
#define TMS_Pin GPIO_PIN_13
#define TMS_GPIO_Port GPIOA
#define TCK_Pin GPIO_PIN_14
#define TCK_GPIO_Port GPIOA
#define RED_Pin GPIO_PIN_10
#define RED_GPIO_Port GPIOC
#define GREEN_Pin GPIO_PIN_12
#define GREEN_GPIO_Port GPIOC
#define BLUE_Pin GPIO_PIN_2
#define BLUE_GPIO_Port GPIOD
#define SWO_Pin GPIO_PIN_3
#define SWO_GPIO_Port GPIOB
#define DIGIT_B2_Pin GPIO_PIN_4
#define DIGIT_B2_GPIO_Port GPIOB
#define DIGIT_B3_Pin GPIO_PIN_5
#define DIGIT_B3_GPIO_Port GPIOB
#define DIGIT_B0_Pin GPIO_PIN_6
#define DIGIT_B0_GPIO_Port GPIOB
#define HCSR04_TRIG_Pin GPIO_PIN_8
#define HCSR04_TRIG_GPIO_Port GPIOB

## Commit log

2026-05-02 README for STM32 Irrigation Controller
    Updated project description, features, hardware details, and architecture for STM32 Irrigation Controller.
2026-05-02 Add firmware, hardware design files, and gitignore
    [ECE298_RS_Adapter - CADCAM Bottom Assembly.GBR, ECE298_RS_Adapter - CADCAM Bottom Copper.GBR, ECE298_RS_Adapter - CADCAM Bottom SMT Paste.GBR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]

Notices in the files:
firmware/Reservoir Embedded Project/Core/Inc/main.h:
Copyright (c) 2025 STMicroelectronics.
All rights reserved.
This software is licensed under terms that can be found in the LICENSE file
